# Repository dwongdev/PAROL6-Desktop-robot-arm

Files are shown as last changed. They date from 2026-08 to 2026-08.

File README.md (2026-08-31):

<div align="center">

# PAROL6-Desktop-robot-arm

</div>



<div align="center">

      Powered by the Robotics Toolbox (https://github.com/petercorke/robotics-toolbox-python) 

<p align="center">
  
  
  
  
  
  
</p>

## [▶️YouTube🔴 Video of Robot in Action!](https://youtu.be/bbrFn3aFLaA)

</div>

## 📖 Project Overview
PAROL6 is a high-performance 3D-printed desktop robotic arm. The design approach of PAROL6 was to be similar to industrial robots in terms of mechanical design, control software, and usability. Control software, GUI, and robots STL files are open-source. 

## How to build / Where to buy?

You can buy the PAROL6 robotic arm on our website: https://source-robotics.com

If you want to Source all the parts yourself and build your own follow these steps:

* Source all the parts from the [BOM](https://github.com/PCrnjak/PAROL6-Desktop-robot-arm/tree/main/BOM)
* Follow [Building instructions](https://github.com/PCrnjak/PAROL6-Desktop-robot-arm/tree/main/Building%20instructions) to assemble your robot
* Follow [DOCS](https://source-robotics.github.io/PAROL-docs/) to get your robot up and running.

## 📚 Resources
- [Official website](https://source-robotics.com)
- [Commander software](https://github.com/PCrnjak/PAROL-commander-software) ------ [Minimal hardware specs!](https://github.com/PCrnjak/PAROL-commander-software/blob/main/confirmed_working_systems.md)
- [PAROL-Web-Commander](https://github.com/Jepson2k/PAROL-Web-Commander) — alternative web-based commander software
- [Python API](https://github.com/PCrnjak/PAROL6-python-API) ; [Python API legacy](https://github.com/PCrnjak/PAROL6-python-API-Alvar)
- [Building instructions](https://github.com/PCrnjak/PAROL6-Desktop-robot-arm/tree/main/Building%20instructions)
- [BOM](https://github.com/PCrnjak/PAROL6-Desktop-robot-arm/tree/main/BOM)
- [DOCS](https://source-robotics.github.io/PAROL-docs/)
- [Video tutorials](https://youtube.com/playlist?list=PLSueoDrBt5MMTL9O8qAWZiJrNIf8-29Qz&si=Zca3UZKENje9ifow)
- [ROS2 / Moveit simulation](https://github.com/PCrnjak/PAROL6-ROS2-MOVEIT)

- [Community projects](community_projects.md) — GUIs, vision/AI demos, and hardware mods built by the community

## 🌐 More about PAROL6 robotic arm

| YouTube | Instagram | Twitter | LinkedIn |
|---|---|---|---|
|  |  |  |  |

| Discord | Forum | Hackaday | Blog |
|---|---|---| ---|
|  |  |  |  

## ⚠️ Safety, Liability & Disclaimer
This project includes experimental software, hardware designs, and assembly documentation that are still under development and may contain bugs, errors, or incomplete features. By using, building, or modifying this project, you acknowledge that:

* You use this project entirely at your own risk
* You are solely responsible for safe assembly, testing, and operation
* No guarantee is made regarding correctness, safety, or reliability
* The authors are not responsible for any damage, injury, or loss resulting from the use or misuse of this project
* Hardware performance and safety depend on user assembly, component quality, calibration, and handling, which cannot be guaranteed
* This project is provided “as is.” If you choose to build a device yourself using these files, designs, or instructions, you do so without any warranties or guarantees, including regarding safety, reliability, or suitability for any particular purpose.

THIS PROJECT INVOLVES LETHAL VOLTAGES AND OTHER SERIOUS HAZARDS THAT CAN CAUSE SEVERE INJURY. YOU MUST READ THE FULL [SAFETY WARNING AND DISCLAIMER DOCUMENT](SAFETY_WARNING_AND_DISCLAIMER.md)  BEFORE USING ANY PROJECT FILES. BY PROCEEDING, YOU ACKNOWLEDGE AND ACCEPT ALL RISKS AND AGREE TO USE THIS PROJECT ENTIRELY AT YOUR OWN RESPONSIBILITY.

## 💸Support us

The majority of this project is open source and freely available to everyone. Your assistance, whether through donations or advice, is highly valued. Thank you!

 


## 🛡️ Licensing
Project is under GPLv3 Licence

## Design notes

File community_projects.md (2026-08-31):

<div align="center">

# 🌍 PAROL6 Community Projects

Software, hardware mods, and experiments built by the community around PAROL6.

[⬅ Back to main README](README.md)

</div>

---

These are third-party projects, not maintained by Source Robotics. Use at your own risk, and check each repo's own license and documentation before building or running anything.

## 🖥️ Control Software & GUIs

| Project | Description |
|---|---|
| [Parol6_Better_Command](https://github.com/thousands-star/Parol6_Better_Command) | Commander software refactored for easier editing, with vision systems |
| [PAROL6 Pilot](https://github.com/jointAxis77/pilot) | Web GUI for controlling PAROL6 |
| [PAROL6_GUI](https://github.com/jakubgrzebien1234-creator/PAROL6_GUI) | Alternative desktop GUI |

## 🤖 Vision & AI

| Project | Description |
|---|---|
| [PAROL6-Python-API-Gemini-Vision-Public](https://github.com/AlvarEhr/PAROL6-Python-API-Gemini-Vision-Public) | Control PAROL6 using Gemini LLM + vision |
| [Tic-Tac-Toe-Robot-Project-Parol6](https://github.com/lennardkiebler-cryptoii/Tic-Tac-Toe-Robot-Project-Parol6/tree/main) | Vision-guided tic-tac-toe playing robot |

## 🔧 Hardware & Mods

| Project | Description |
|---|---|
| [parol6-printed-eg17](https://github.com/Pixelgamer4k/parol6-printed-eg17) | Printed part / hardware mod for PAROL6 |

---

## ➕ Add your project

Built something with PAROL6? Open a pull request adding a row to the relevant table above (or a new category if it doesn't fit), following the existing `[Name](link) | Short description` format.

</content>
</invoke>

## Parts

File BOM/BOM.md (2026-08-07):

# PAROL6 – Bill of Materials (BOM)

This file contains all the parts you need to build the PAROL6 robot!

Most items have links where you can buy the item, and some of them are affiliate links. Items like screws, belts and bearings can be bought locally or from many other vendors.

> [!NOTE]
> If any product links are broken, unavailable, or no longer point to the correct item, please [open an issue](https://github.com/PCrnjak/PAROL6-Desktop-robot-arm/issues/new). You can also use the reference images to find the same or an equivalent part from another supplier.

---

## Screws and Nuts

| Diameter / Type | Length | Quantity | Description |
| :--- | :--- | :--- | :--- |
| M4 | 10 mm | 20 | DIN 912 / ISO 4762 (hexagon socket head cap) |
| M3 | 8 mm | 10 | 2 mm head height |
| M3 | 8 mm | 50 | DIN 912 / ISO 4762 (hexagon socket head cap) |
| M3 | 14 mm | 30 | DIN 912 / ISO 4762 (hexagon socket head cap) |
| M3 nut | — | 10 | DIN 912 / ISO 4762 (hexagon socket head cap) |
| M3 | 25 mm | 10 | DIN 912 / ISO 4762 (hexagon socket head cap) |
| M2 | 10 mm | 10 | DIN 912 / ISO 4762 (hexagon socket head cap) |
| M3 | 16 mm | 10 | DIN 912 / ISO 4762 (hexagon socket head cap) |
| M3 | 6 mm | 10 | Pan head phillips |
| M3 | 12 mm | 30 | DIN 912 / ISO 4762 (hexagon socket head cap) |
| M3 | 35 mm | 10 | DIN 912 / ISO 4762 (hexagon socket head cap) |
| M4 | 16 mm | 30 | DIN 912 / ISO 4762 (hexagon socket head cap) |
| M4 | 14 mm | 10 | DIN 912 / ISO 4762 (hexagon socket head cap) |
| M4 | 50 mm | 10 | DIN 912 / ISO 4762 (hexagon socket head cap) |
| M3 | 15 mm | 2 | Tapered screw head |

---

## Gearboxes

> [!NOTE]
> For cheaper gearbox options you can use MG series planetary gearboxes. They have bigger backlash but are cheaper. [Link](https://www.omc-stepperonline.com/mg-series-planetary-gearbox) — [Aliexpress Link](https://s.click.aliexpress.com/e/_oBYBoUP)

| Name | Type | Quantity | Description | Link | ALT link | Reference Image |
| :--- | :--- | :--- | :--- | :--- | :--- | :--- |
| Gearbox 20:1 | Nema 17 20:1 | 2 | EG precision planetary | [Link](https://www.omc-stepperonline.com/eg-series-planetary-gearbox-gear-ratio-20-1-backlash-20-arc-min-for-nema-17-stepper-motor-eg17-g20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) | [Alt Link](https://s.click.aliexpress.com/e/_oEhMNU5) | [Link](BOM%20reference%20images/stepper%2020_1.jpg) |
| Gearbox 10:1 | Nema 17 10:1 | 1 | EG precision planetary | [Link](https://www.omc-stepperonline.com/eg-series-planetary-gearbox-gear-ratio-10-1-backlash-15-arc-min-for-nema-17-stepper-motor-eg17-g10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) | [Alt Link](https://s.click.aliexpress.com/e/_oEhMNU5) | [Link](BOM%20reference%20images/stepper%2010_1.jpg) |

---

## Motors

| Name | Type | Quantity | Description | Link | ALT link | Reference Image |
| :--- | :--- | :--- | :--- | :--- | :--- | :--- |
| Stepper 1 | Nema 17 | 1 | 16Ncm, 42x42x20mm | [Link](https://www.omc-stepperonline.com/nema-17-bipolar-1-8deg-16ncm-22-6oz-in-1a-3-7v-42x42x20mm-4-wires-17hs08-1004s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) | [Alt Link](https://s.click.aliexpress.com/e/_oo1LTs7) | [Link](BOM%20reference%20images/stepper%2021_5mm.jpg) |
| Stepper 2 | Nema 17 | 3 | 45Ncm, 42x42x40mm | [Link](https://www.omc-stepperonline.com/nema-17-bipolar-45ncm-64oz-in-2a-42x42x40mm-4-wires-w-1m-cable-connector-17hs16-2004s1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) | [Alt Link](https://s.click.aliexpress.com/e/_oC1Ii0v) | [Link](BOM%20reference%20images/stepper%2040mm.jpg) |
| Stepper 3 | Nema 17 | 2 | 65Ncm, 42x42x60mm | [Link](https://www.omc-stepperonline.com/nema-17-bipolar-1-8deg-65ncm-92oz-in-2-1a-3-36v-42x42x60mm-4-wires-17hs24-2104s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) | [Alt Link](https://s.click.aliexpress.com/e/_opq2ugp) | [Link](BOM%20reference%20images/stepper%2060mm.jpg) |

---

## Belts

| Name | Type | Quantity | Description | Link | ALT link | Reference Image |
| :--- | :--- | :--- | :--- | :--- | :--- | :--- |
| Joint 1 belt | HTD3 396 | 1 | 6 mm width | [Link](https://s.click.aliexpress.com/e/_c3LnffKl) | | [Link](BOM%20reference%20images/HTD%203M%20belt.png) |
| Joint 3 belt | HTD3 342 | 1 | 6 mm width | [Link](https://s.click.aliexpress.com/e/_c4O7CHOd) | | [Link](BOM%20reference%20images/HTD%203M%20belt.png) |
| Joint 4 belt | HTD3 201 | 1 | 6 mm width | [Link](https://s.click.aliexpress.com/e/_c4NiUycd) | | [Link](BOM%20reference%20images/HTD%203M%20belt.png) |
| Joint 5 belt | HTD3 246 | 1 | 6 mm width | [Link](https://s.click.aliexpress.com/e/_c4DlcQaD) | | [Link](BOM%20reference%20images/HTD%203M%20belt.png) |

---

## Pulleys

| Name | Type | Quantity | Description | Link | ALT link | Reference Image |
| :--- | :--- | :--- | :--- | :--- | :--- | :--- |
| J4 pulley, J5 pulley | HTD3M 12 tooth | 2 | 5mm bore, 10mm width | [Link](https://s.click.aliexpress.com/e/_DFYERWX) | | [Link](BOM%20reference%20images/HTD%203M%20pulley.png) |
| J1 pulley | HTD3M 15 tooth | 1 | 5mm bore, 10mm width | [Link](https://s.click.aliexpress.com/e/_DBVgkVp) | | [Link](BOM%20reference%20images/HTD%203M%20pulley.png) |

---

## Shaft couplers

| Name | Type | Quantity | Description | Link | ALT link | Reference Image |
| :--- | :--- | :--- | :--- | :--- | :--- | :--- |
| Shaft coupler | Shaft coupler | 3 | 8 mm hole shaft, M4 screw holes | [Link](https://s.click.aliexpress.com/e/_c2xnQgI7) | | [Link](BOM%20reference%20images/shaft%20coupler%20gripper.png) |

---

## Bearings

| Name | Type | Quantity | Description | Link | ALT link | Reference Image |
| :--- | :--- | :--- | :--- | :--- | :--- | :--- |
| Bearing 1 | AXK3552 | 1 | 35X52X4, needs to have top and bottom plate | [Link](https://s.click.aliexpress.com/e/_Dk4bHg7) | | [Link](BOM%20reference%20images/AXK3552%20needle%20bearing.png) |
| Bearing 2 | NSK HR32906J | 5 | Joint 5, 4 and 3 | [Link](https://s.click.aliexpress.com/e/_DcJMtBl) | | [Link](BOM%20reference%20images/Tapered%20bearing.png) |
| Bearing 3 | NSK HR32907J | 4 | Joint 1 and 2 | [Link](https://s.click.aliexpress.com/e/_DcJMtBl) | | [Link](BOM%20reference%20images/Tapered%20bearing.png) |
| Tension bearing | Ball bearing 3x8x4 | 20 | Used for belt tension | [Link](https://s.click.aliexpress.com/e/_DCjfgFV) | | [Link](BOM%20reference%20images/small%20tension%20bearings.png) |
| Tension bearing | Ball bearing 3x10x4 | 20 | Used for belt tension | [Link](https://s.click.aliexpress.com/e/_DlA33Af) | | [Link](BOM%20reference%20images/small%20tension%20bearings.png) |

---

## Electronics

| Name | Type | Quantity | Description | Link | ALT link | Reference Image |
| :--- | :--- | :--- | :--- | :--- | :--- | :--- |
| PAROL control board | | 1 | [source-robotics.com](http://source-robotics.com/) | [Link](https://source-robotics.com/products/parol6-control-board) | | |
| TMC5160 | | 6 | Drivers from the links are tested. Use any other at own risk | [Link](https://s.click.aliexpress.com/e/_c3Jc52V9) | [Alt Link](https://s.click.aliexpress.com/e/_Dd8Cjkb) | |
| Thermal paste / cement | | 2 | Needed only if your control board has no drivers! | [Link](https://s.click.aliexpress.com/e/_c2u86OEn) | | [Link](BOM%20reference%20images/Thermal%20cement.jpg) |
| On/Off button | | 1 | 12mm 3-6V | [Link](https://s.click.aliexpress.com/e/_DBpZV3h) | | [Link](BOM%20reference%20images/button.png) |
| JST PH 2.0mm 200mm 4PIN | | 1 | For power button | [Link](https://s.click.aliexpress.com/e/_DeObQ1D) | | [Link](BOM%20reference%20images/JST_PH.png) |
| Noctua NF-A4x20 5V 40mm | | 1 | or any 40mm 5V fan| | | |
| Power connector - male + female | | 1 | GX16 2PIN | [Link](https://s.click.aliexpress.com/e/_DcHjMfN) | | [Link](BOM%20reference%20images/GX16.jpg) |
| Gripper connector (electric) | | 1 | M8 sensor Female 4 pin | [Link](https://s.click.aliexpress.com/e/_DDQz9iP) | | [Link](BOM%20reference%20images/M8%20connector%20female%204pin.png) |
| Power supply | | 1 | Any 24V 5A supply | [Link](https://www.omc-stepperonline.com/edr-120-24-mean-well-120w-24vdc-5a-115-230vac-din-rail-power-supply-edr-120-24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) | [Alt Link](https://s.click.aliexpress.com/e/_olFOM5Z) | |
| Limit switches | | 3 | Type ZW12-3 | [Link](https://s.click.aliexpress.com/e/_DBq6eeF) | | [Link](BOM%20reference%20images/LIMIT_SWITCH.png) |
| Inductive sensor 1 | | 1 | 4mm NPN NO | [Link](https://s.click.aliexpress.com/e/_c40MRkk5) | [Alt Link](https://s.click.aliexpress.com/e/_c3CMbO1h) | [Link](BOM%20reference%20images/INDUCTIVE_4MM.png) |
| Inductive sensor 2 | | 1 | GX-F8A | [Link](https://s.click.aliexpress.com/e/_c4VxLtW3) | | [Link](BOM%20reference%20images/GX-F8A.png) |
| Inductive sensor 3 | | 1 | M5, NPN NO | [Link](https://s.click.aliexpress.com/e/_c3zGvxrP) | [Alt Link](https://s.click.aliexpress.com/e/_c3CMbO1h) | [Link](BOM%20reference%20images/INDUCTIVE_5MM.png) |
| Estop | | 1 | Any NC estop | [Link](https://s.click.aliexpress.com/e/_c3Bn4RR5) | | [Link](BOM%20reference%20images/19mm%20ESTOP.png) |
| Cable gland for estop | | 1 | PG7 type | [Link](https://s.click.aliexpress.com/e/_DdJj62p) | | [Link](BOM%20reference%20images/CABLE_GLAND.png) |
| M3 brass insert | | 4 | M3, 6mm lenght | [Link](https://s.click.aliexpress.com/e/_DmZR9AN) | | [Link](BOM%20reference%20images/brass_insert.png) |
| Pneumatic connector - robot | | 4 | 4 mm type PM | [Link](https://s.click.aliexpress.com/e/_c3GpN5cR) | | [Link](BOM%20reference%20images/PM4.png) |
| Pneumatic Gripper | | 1 | MHZ2-16D | [Link](https://s.click.aliexpress.com/e/_c4EJl0Qr) | | [Link](BOM%20reference%20images/MHZ.png) |
| Pneumatic gripper connector | | 2 | PC4 - M5 | [Link](https://s.click.aliexpress.com/e/_DkCJqUL) | | [Link](BOM%20reference%20images/PC4-M5.png) |
| Pneumatic tube | | 5 meters | 1 meter, 4x2.5mm | [Link](https://s.click.aliexpress.com/e/_DEhvFyJ) | | [Link](BOM%20reference%20images/Pneumatic_tube.png) |
| xt30 connector female | | 1 | Used to deliver power to PAROL6 PCB | [Link](https://s.click.aliexpress.com/e/_DllR7eL) | | |
| Stlink / programming adapter | | 1 | Use our [Official programming adapter](https://source-robotics.com/products/parol6-programming-adapter) for ease of use! Pin order needs to be: SWCLK, SWDIO, GND, 3V3, 5V | [Link](https://s.click.aliexpress.com/e/_DCPwBnn) | | |
| USB B cable | | 1 | Comms to the PC | | | |
| 5/2 solenoid air valve | | 1 | 4mm tube connectors, 5/2, 24V | [Link](https://s.click.aliexpress.com/e/_DDrw0Ux) | | [Link](BOM%20reference%20images/solenoid_valve.png) |

---

## Vacuum gripper

| Name | Type | Quantity | Description | Link | ALT link | Reference Image |
| :--- | :--- | :--- | :--- | :--- | :--- | :--- |
| Suction cup gripper | | 1 | | [Link](https://www.aliexpress.com/item/4000538850003.html) | | |
| Vacuum generator | | 1 | | [Link](https://s.click.aliexpress.com/e/_DdTAyOZ) | | |
| 4mm to 6mm coupler | | 1 | | [Link](https://s.click.aliexpress.com/e/_DeEEqHR) | | |

---

## Small print bed modification

> [!NOTE]
> These parts are only needed if your printer bed is too small for `J1_turret_rework_blocker` and `Upper_arm`. Both parts are split in two and joined with dowel pins and epoxy after printing. STL files are in [STL/SMALL_PRINT_BED](../STL/SMALL_PRINT_BED). Nothing else in the build changes.

| Name | Type | Quantity | Description | Link | ALT link | Reference Image |
| :--- | :--- | :--- | :--- | :--- | :--- | :--- |
| J1 turret dowel pin | Dowel pin 4 x 18 mm | 3 | Solid cylindrical, stainless or hardened steel | [Link](https://www.aliexpress.com/item/1005009401701158.html) | | |
| Upper arm dowel pin | Dowel pin 6 x 22 mm | 4 | Solid cylindrical, stainless or hardened steel | [Link](https://www.aliexpress.com/item/1005009401701158.html) | | |
| Two part epoxy | Epoxy adhesive | 1 | 1:1 mix, slow setting | [Link](https://www.aliexpress.com/item/1005012397836514.html) | | |

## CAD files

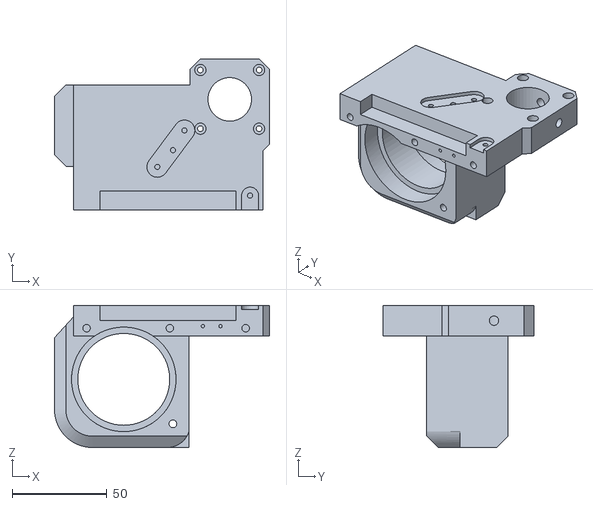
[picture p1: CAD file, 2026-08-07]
STL/SMALL_PRINT_BED/J1_turret_rework_blocker/J1_turret_rework_blocker_B_arm_end.STL
113.5 x 79.5 x 75.0

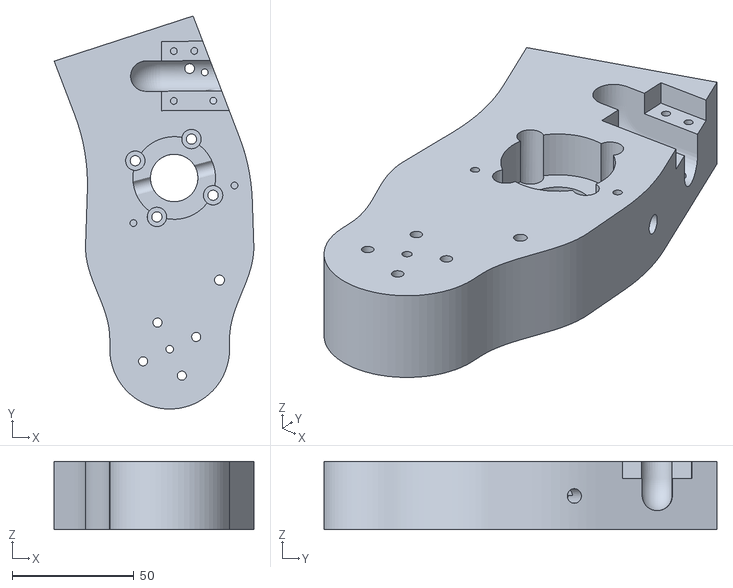
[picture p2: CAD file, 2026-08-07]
STL/SMALL_PRINT_BED/Upper_arm/Upper_arm_A_long_end.STL
82.1 x 161.6 x 28.0

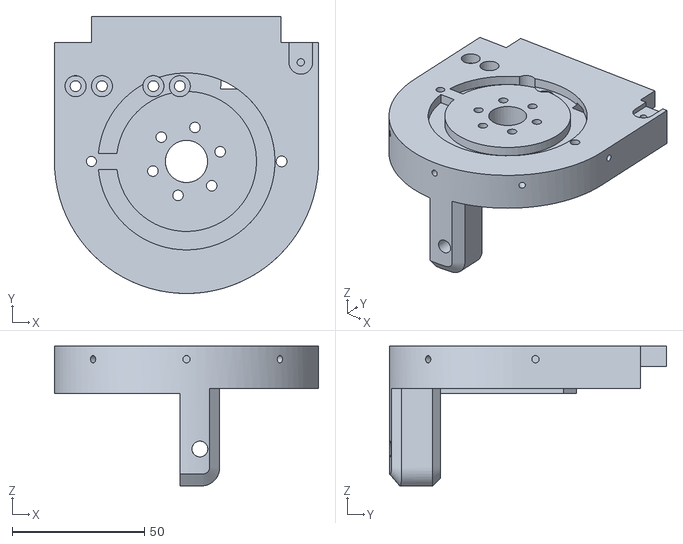
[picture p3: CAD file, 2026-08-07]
STL/SMALL_PRINT_BED/J1_turret_rework_blocker/J1_turret_rework_blocker_A_turret_end.STL
100.0 x 104.9 x 53.0

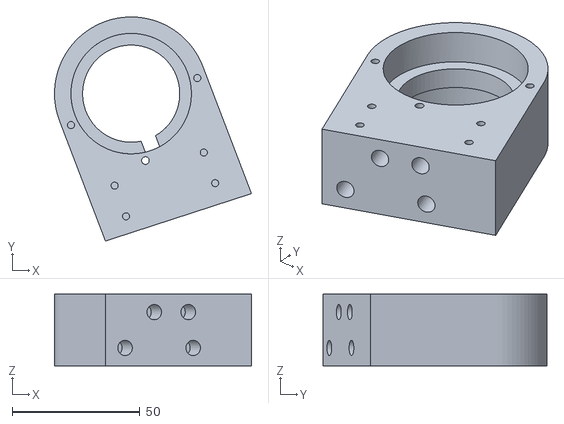
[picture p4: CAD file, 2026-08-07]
STL/SMALL_PRINT_BED/Upper_arm/Upper_arm_B_short_end.STL
77.1 x 87.7 x 28.0

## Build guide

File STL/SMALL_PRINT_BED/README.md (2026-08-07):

# Small print bed modification

These STL files are **replacements**, not additions.

`Upper_arm` and `J1_turret_rework_blocker` do not fit on a printer with a bed
smaller than about 175 mm. No rotation makes them fit: the smallest cube that
can contain the upper arm is 160.5 mm, and the turret blocker 154.1 mm.

Each part here is split into two halves that are joined with steel dowel pins
and two part epoxy after printing.

> [!IMPORTANT]
> Only use these files if your printer bed is too small for the standard parts.
> If the original parts fit, print those instead. A single moulded part is always
> stronger than a bonded one.

## Contents

| Folder | Replaces | Halves |
| :--- | :--- | :--- |
| `Upper_arm` | `STL/UPPER_ARM/Upper_arm.STL` | `Upper_arm_A_long_end.STL`, `Upper_arm_B_short_end.STL` |
| `J1_turret_rework_blocker` | `STL/SHOULDER/J1_turret_rework_blocker.STL` | `J1_turret_rework_blocker_A_turret_end.STL`, `J1_turret_rework_blocker_B_arm_end.STL` |

Print one folder or both, depending on which parts do not fit. Every other part
of the robot is unchanged.

## Before you print

Read `Building instructions/Parol small print bed modification.pdf` first. It
covers the reamers, dowel pins and epoxy you need, and the assembly steps for
both parts.

The extra hardware is listed under **Small print bed modification** in
`BOM/BOM.md`.

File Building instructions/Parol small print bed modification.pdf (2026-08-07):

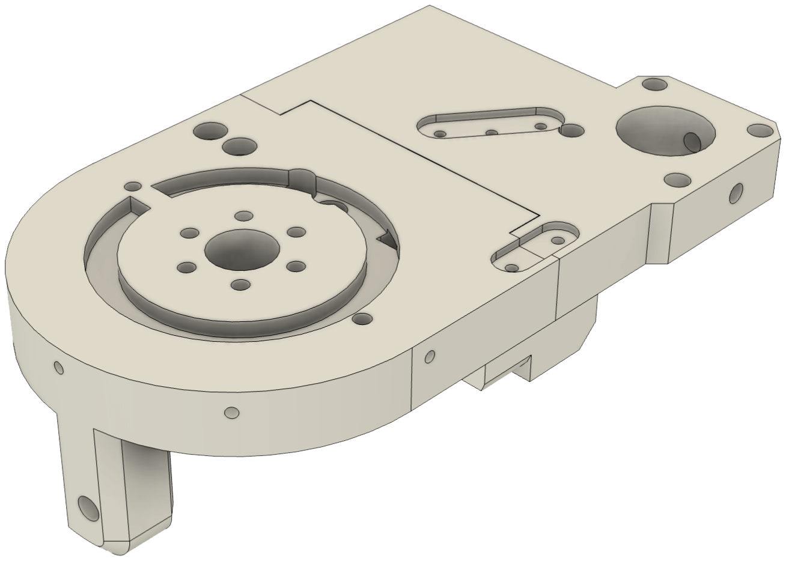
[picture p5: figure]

# PAROL6 SMALL PRINT BED MODIFICATION

Splitting J1_turret_rework_blocker and Upper_arm for printers with a bed smaller than 175 mm

# About this modification

Parts affected
Upper_arm
102 x 231 x 28 mm
J1_turret_rework_blocker
114 x 175 x 75 mm

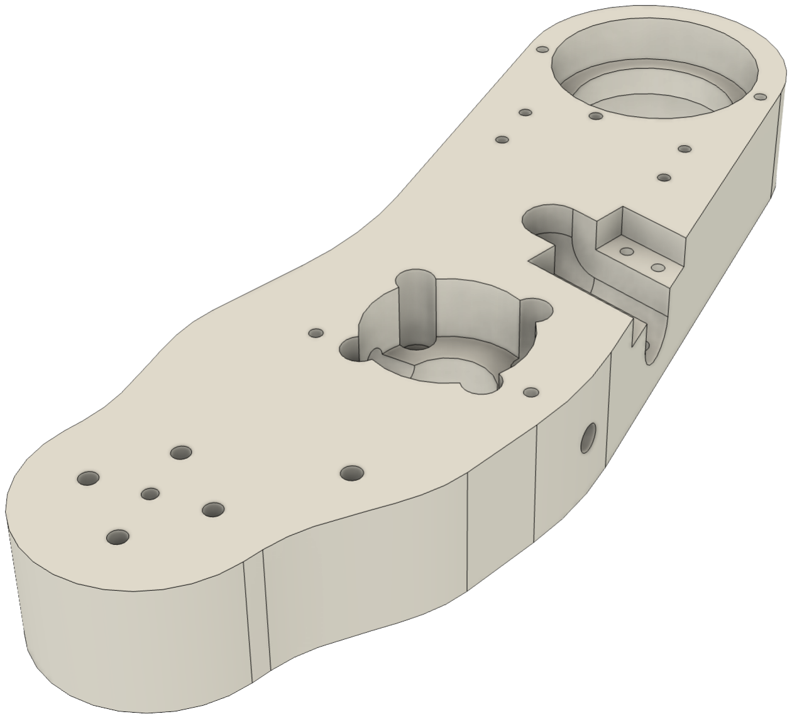
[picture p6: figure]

Both exceed a 150 mm cube.

Two PAROL6 parts do not fit on a 150 mm printer. No rotation makes them fit: the smallest cube that can contain the upper arm is 160.5 mm, and the turret blocker 154.1 mm.

This modification splits each part in two, at a plane chosen to miss every screw hole. The halves are located with steel dowel pins and bonded with two part epoxy.

No other part of the robot changes. Assembly of the arm itself follows the main manual exactly.

# Required materials

# Tools required

Tools
4 mm H7 chucking reamer
6 mm H7 chucking reamer
Tap wrench, 12 mm capacity Hobby knife or deburring tool Flat reference surface
4 to 6 spring clamps

Printed holes come out undersize and out of round, especially horizontal ones. Reaming gives the dowel pins a hole they can actually locate in.

Both reamers have round shanks, so you need a tap wrench with at least 12 mm capacity. Do not turn them in a power drill: PETG melts, the hole closes behind the cutter and the reamer grabs.

Turn clockwise going in AND clockwise coming out. Reversing a reamer dulls it and tears the hole.

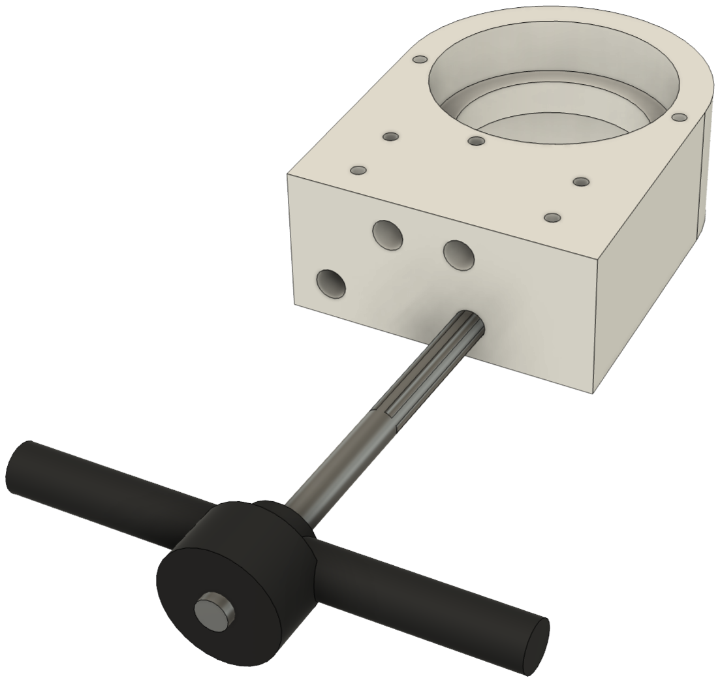
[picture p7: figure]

A 4 mm and 6 mm drill bit turned by hand will work, but cuts oversize and less round.

# Consumables

Consumables
3 x dowel pin 4 x 18 mm
4 x dowel pin 6 x 22 mm
Two part epoxy, slow set
120 grit sandpaper
99% isopropyl alcohol
Nitrile gloves, swabs, sticks

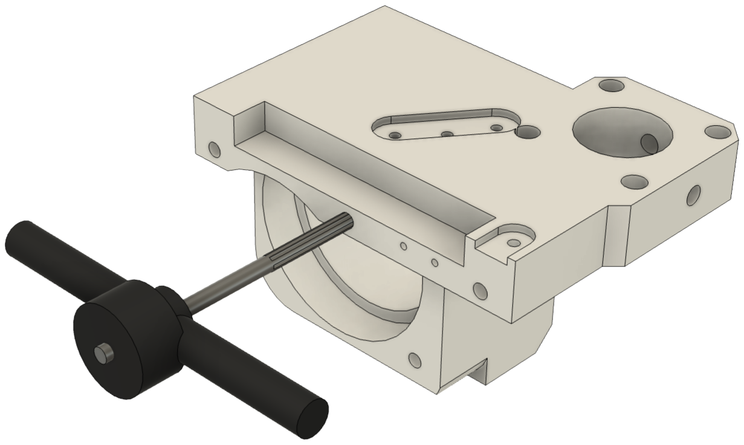
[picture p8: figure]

Pins must be SOLID dowel pins, stainless or hardened steel. Do not use roll pins or spring pins: they are rolled tube, they compress, and they cannot locate anything.

Use a slow setting two part epoxy. Five minute epoxy starts to gel before you have placed four pins and closed a 60 mm seam.

Do not use cyanoacrylate. It bonds PETG poorly and has no gap filling ability.

# Printing the parts

# Printing the parts

Printed parts

Upper_arm_A_long_end
137 x 136 mm
Upper_arm_B_short_end
82 x 63 mm
J1_turret_rework_blocker_A_turret_end 100 x 105 mm
J1_turret_rework_blocker_B_arm_end 114 x 80 mm

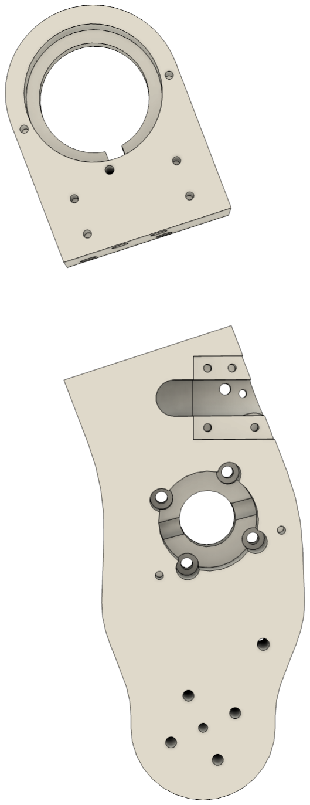
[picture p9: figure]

Print all four halves in PETG, using the infill and settings from the main printing table.

Lay each half with its largest flat face on the bed. Upper arm part A is the tightest at 137 x 136 mm, so rotate it on the bed and use a brim rather than a raft.

Clean off the brim and check for elephant foot before doing anything else. A raised first layer edge on a mating face will hold the seam open.

# Upper arm

# Step 1 - Upper arm - ream the dowel holes

This step
6 mm H7 reamer
Tap wrench

Part A 4 holes, 11 mm deep Part B 4 holes, 13 mm deep Total 8 holes

Ream all eight 6 mm holes, four in each half.

Hold the reamer square to the seam face and turn it steadily by hand. Back it out every few turns to clear chips, which come off PETG stringy and pack the flutes.

Clockwise in, clockwise out. Never reverse.

Test each hole with a pin. You want a firm slip fit: in under thumb pressure, staying put when you turn the part over.

# Step 2 - Upper arm - sand and degrease

This step
120 grit sandpaper
99% isopropyl alcohol
Nitrile gloves

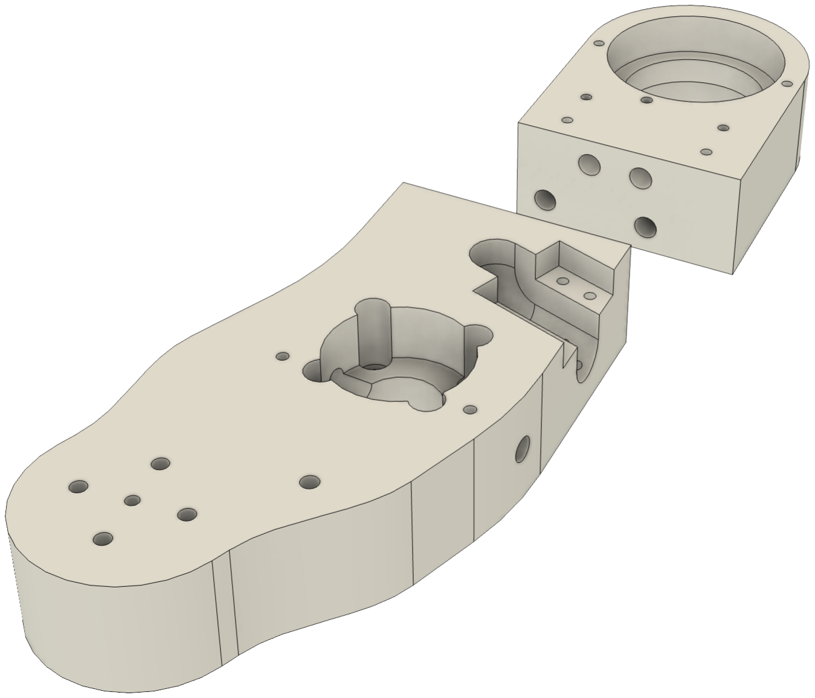
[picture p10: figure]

Sand both seam faces

Scuff both seam faces with 120 grit until they are uniformly dull. Any patch left glossy is a patch the epoxy will not grip.

This step does more for joint strength than the choice of adhesive.

Do not sand inside the pin holes, you just reamed them.

Wipe both faces with isopropyl, let it flash off, then keep bare fingers off them. Gloves on from here.

# Step 3 - Upper arm - dry fit

This step
Upper_arm_A_long_end
Upper_arm_B_short_end
4 x dowel pin 6 x 22 mm

No glue at this stage

Seat all four pins in part B first. B takes 13 mm of a 22 mm pin, leaving 9 mm to enter an 11 mm hole in A, so the pins can never bottom out and hold the seam open.

Push the halves together by hand. Look along the seam from several angles: it should close with no visible gap and no light through it.

Stand the assembly on a flat surface and check it does not rock.

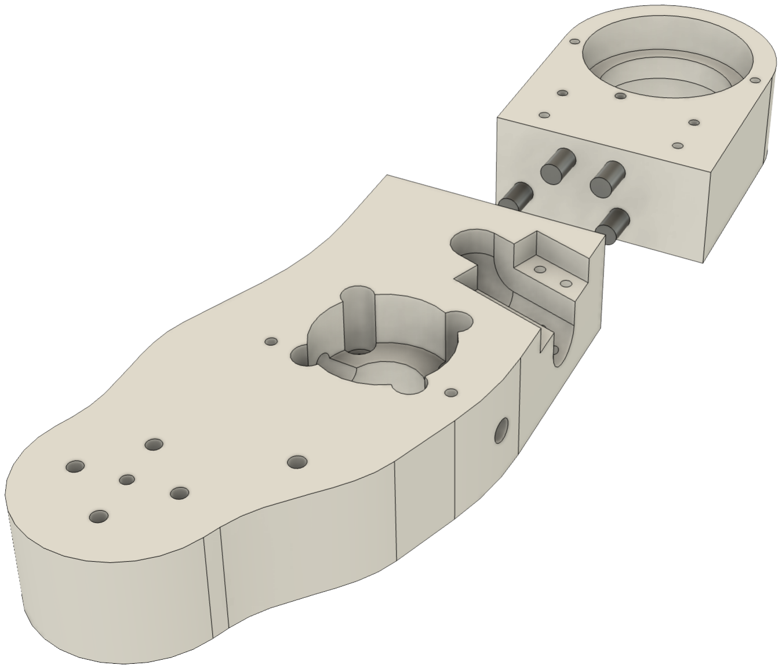
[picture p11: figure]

If the seam will not close, find out why now. Usually elephant foot on a mating face.

# Step 4 - Upper arm - glue and clamp

This step
Two part epoxy
4 x dowel pin 6 x 22 mm
Spring clamps or tape

Set 4-6 h, full cure 24 h

Mix the epoxy for a full two minutes until the colour is even with no streaks. You need well under 1 ml.

Thin coat on BOTH seam faces. Wipe a light film on each pin and drop it in. Do NOT fill the pin holes: a close pin in a blind hole full of paste epoxy hydraulic locks and stops short.

Close the joint and clamp perpendicular to the seam face, not along the part. Tape across the joint handles the 18 degree angle better than a clamp. Snug, not crushing.

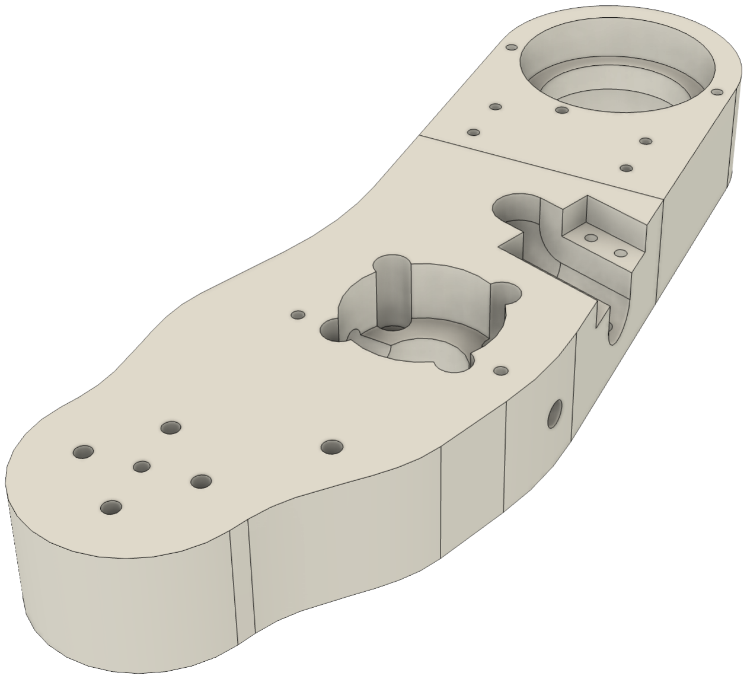
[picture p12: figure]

Wipe squeeze out with isopropyl NOW. Cured epoxy is very hard to remove from PETG.

# J1 turret

# Step 1 - J1 turret - ream the dowel holes

This step
4 mm H7 reamer
Tap wrench

Part A 3 holes, 7 mm deep
Part B 3 holes, 12 mm deep Total 6 holes

Ream all six 4 mm holes, three in each half.

Same technique as the arm: square to the face, steady hand pressure, clear chips often, clockwise in and clockwise out.

Do not confuse the reamers. The 4 mm one is for this part, the 6 mm one for the arm.

Test each hole with a 4 x 18 pin before moving on.

# Step 2 - J1 turret - sand and degrease

This step
120 grit sandpaper
99% isopropyl alcohol
Nitrile gloves

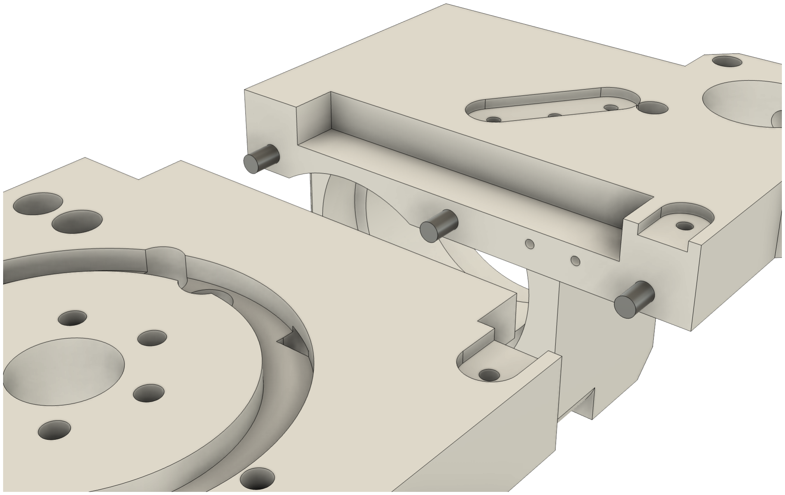
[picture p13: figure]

Butt face, lap face,
tongue end and sides

This part has four surfaces to prepare, not one: the lower butt face, the horizontal lap face, the tongue end face, and the tongue side walls.

Scuff every one of them with 120 grit until uniformly dull, then wipe with isopropyl and let it flash off.

Keep the paper out of the reamed pin holes.

Gloves on once the faces are clean.

# Step 3 - J1 turret - dry fit

This step
J1_turret_rework_blocker_A_turret_end J1_turret_rework_blocker_B_arm_end 3 x dowel pin 4 x 18 mm

No glue at this stage

Seat all three pins in part B, which takes 12 mm of an 18 mm pin. The remaining 6 mm enters a 7 mm hole in A.

Bring the halves together. The lap tongue on A has to slide into the notch in B. It is modelled with 0.15 mm clearance on all three lap faces.

If it binds, sand the TONGUE, not the notch.

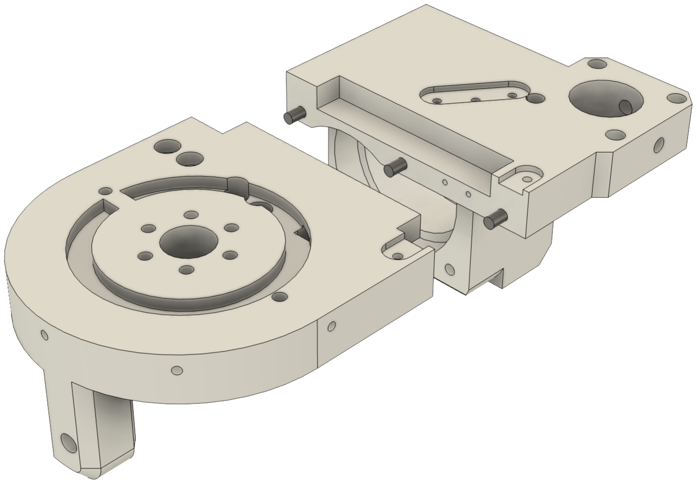
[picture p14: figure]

The notch is much harder to reach than the tongue. Small passes, re-test between each.

# Step 4 - J1 turret - glue and clamp

This step
Two part epoxy
3 x dowel pin 4 x 18 mm
Spring clamps

Set 4-6 h, full cure 24 h

Coat the butt face, the lap face and the tongue end. All three are structural.

Seat the pins in B, wipe a film on each, and do not fill the holes.

Close the joint and clamp along the part axis, straight across the butt seam. The lap step handles alignment in Z by itself, which is why this joint is more forgiving than the arm.

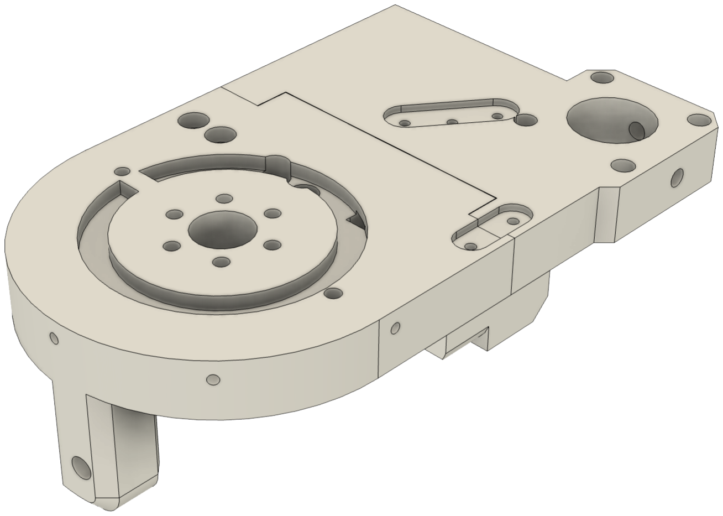
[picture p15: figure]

Wipe squeeze out with isopropyl while it is still wet.

# Step 5 - J1 turret - drill the pilot holes

This step
1.8 mm drill bit

Two pilots cross the seam
Drill AFTER full cure

Two 1.8 mm screw pilots run along the seam axis and are crossed by the cut. Their bores are geometrically unchanged, but drill them through only after the epoxy has fully cured.

Your printer cannot hold 1.8 mm anyway, so these needed drilling regardless. Doing it after the glue up makes the seam irrelevant to the result.

Use the printed holes as your guide and go slowly.

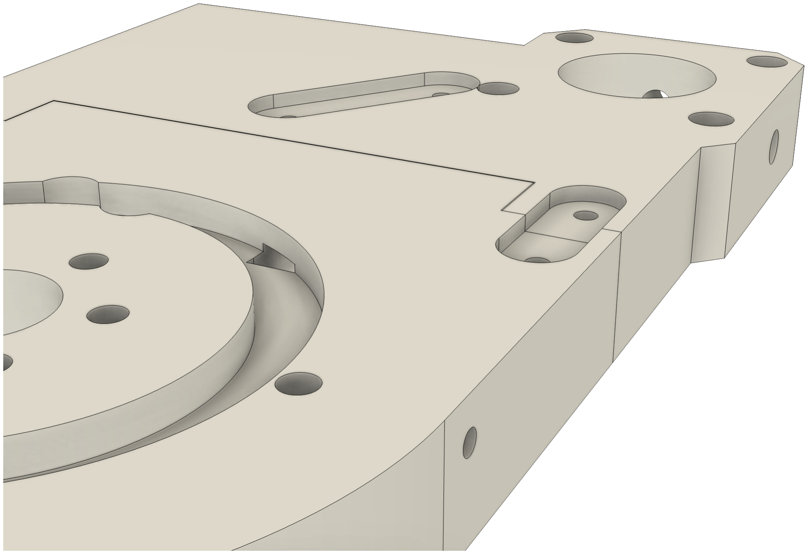
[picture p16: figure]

Also check the large bore the seam crosses. Scrape any step or squeeze out flush.

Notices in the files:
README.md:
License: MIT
